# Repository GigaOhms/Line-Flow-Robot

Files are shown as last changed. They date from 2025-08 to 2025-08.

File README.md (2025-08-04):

# Line Flow Bot

**Line Flow Bot** là một robot dò line mini được thiết kế để học tập và nghiên cứu về PCB design, các thuật toán điều khiển nhúng PID, RTOS. Dự án này được tham khảo và chỉnh sửa từ project: [Mini Line Flow Robot – MQCR Excel](https://bitbucket.org/mqcrexcel/mini-line-flow-robot/).

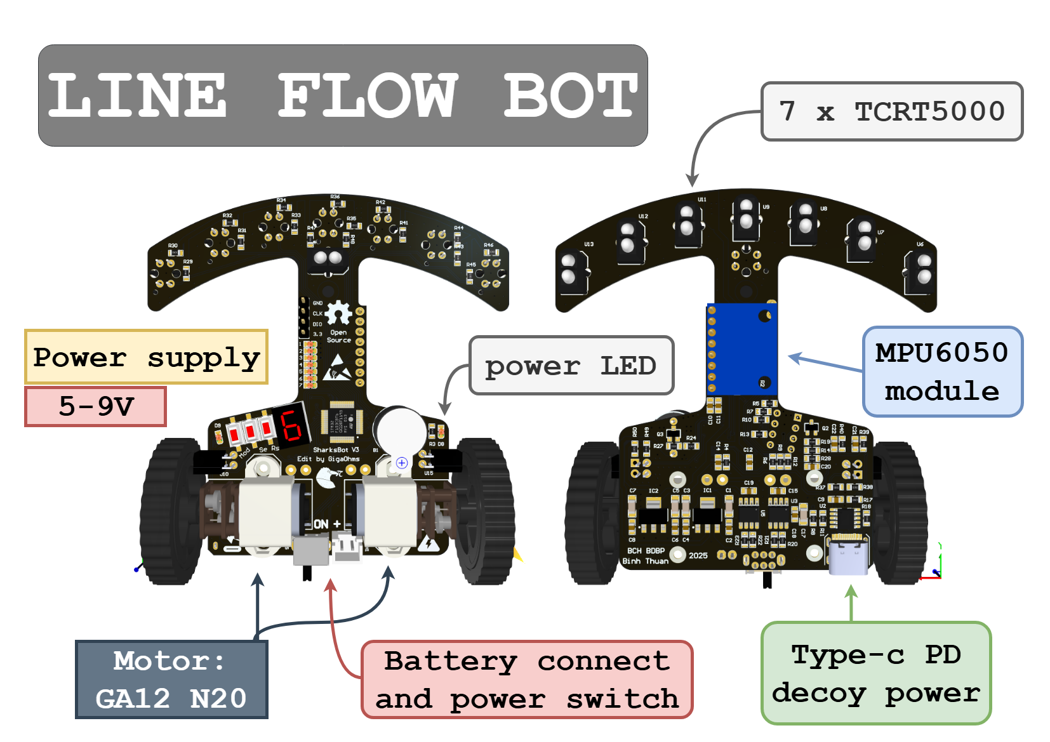
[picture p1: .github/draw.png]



---

## 🧠 Vi điều khiển (MCU)

- **STM32F103C8T6**: ARM Cortex-M3
- Tốc độ xung nhịp: 72 MHz

---

## 🔋 Cấp nguồn

- Điện áp hoạt động: **5–9V**, từ pin Li-ion/LiPo hoặc usb type-C PD protocol.
- Mạch cấp nguồn gồm:
  - **2 x AMS1117**: chuyển từ 5V hoặc 9V xuống 5V và 3.3V 
  - **CH224K (USB Type-C PD Sink)**: cấu hình lấy ra 9V từ cổng USB PD thông qua thiết lập cấu hình điện trở.
  - Công tắc nguồn

---

## ⚙️ Phần cứng chính

### 🚗 Động cơ

- **2 x GA12 N20 500 RPM**
  - Điện áp hoạt động: 5-9V
  - Kết nối qua mạch **2 cầu H** sử dụng **L9110S**

### 🔍 Cảm biến dò line

- **8 x TCRT5000**
  - 7 cảm biến dùng để dò line đen-trắng
  - 1 cảm biến riêng để nhận tín hiệu bắt đầu

### 📦 Cảm biến gia tốc

- **GY-521 (MPU6050)**
  - Gia tốc kế + con quay hồi chuyển (6 DOF)
  - Giao tiếp I2C

### 📟 Hiển thị

- **LED 7 đoạn**
- **LED trạng thái rời**
- **LED nguồn 9V PD decoy**

### 🔘 Nút nhấn

- 2 nút nhấn dùng để cấu hình chế độ chạy hoặc hiệu chỉnh cảm biến

---

## 🧩 Giao tiếp và kết nối

- **SWD**: giao tiếp nạp chương trình và debug cho STM32
- **I2C**: giao tiếp với MPU6050

---

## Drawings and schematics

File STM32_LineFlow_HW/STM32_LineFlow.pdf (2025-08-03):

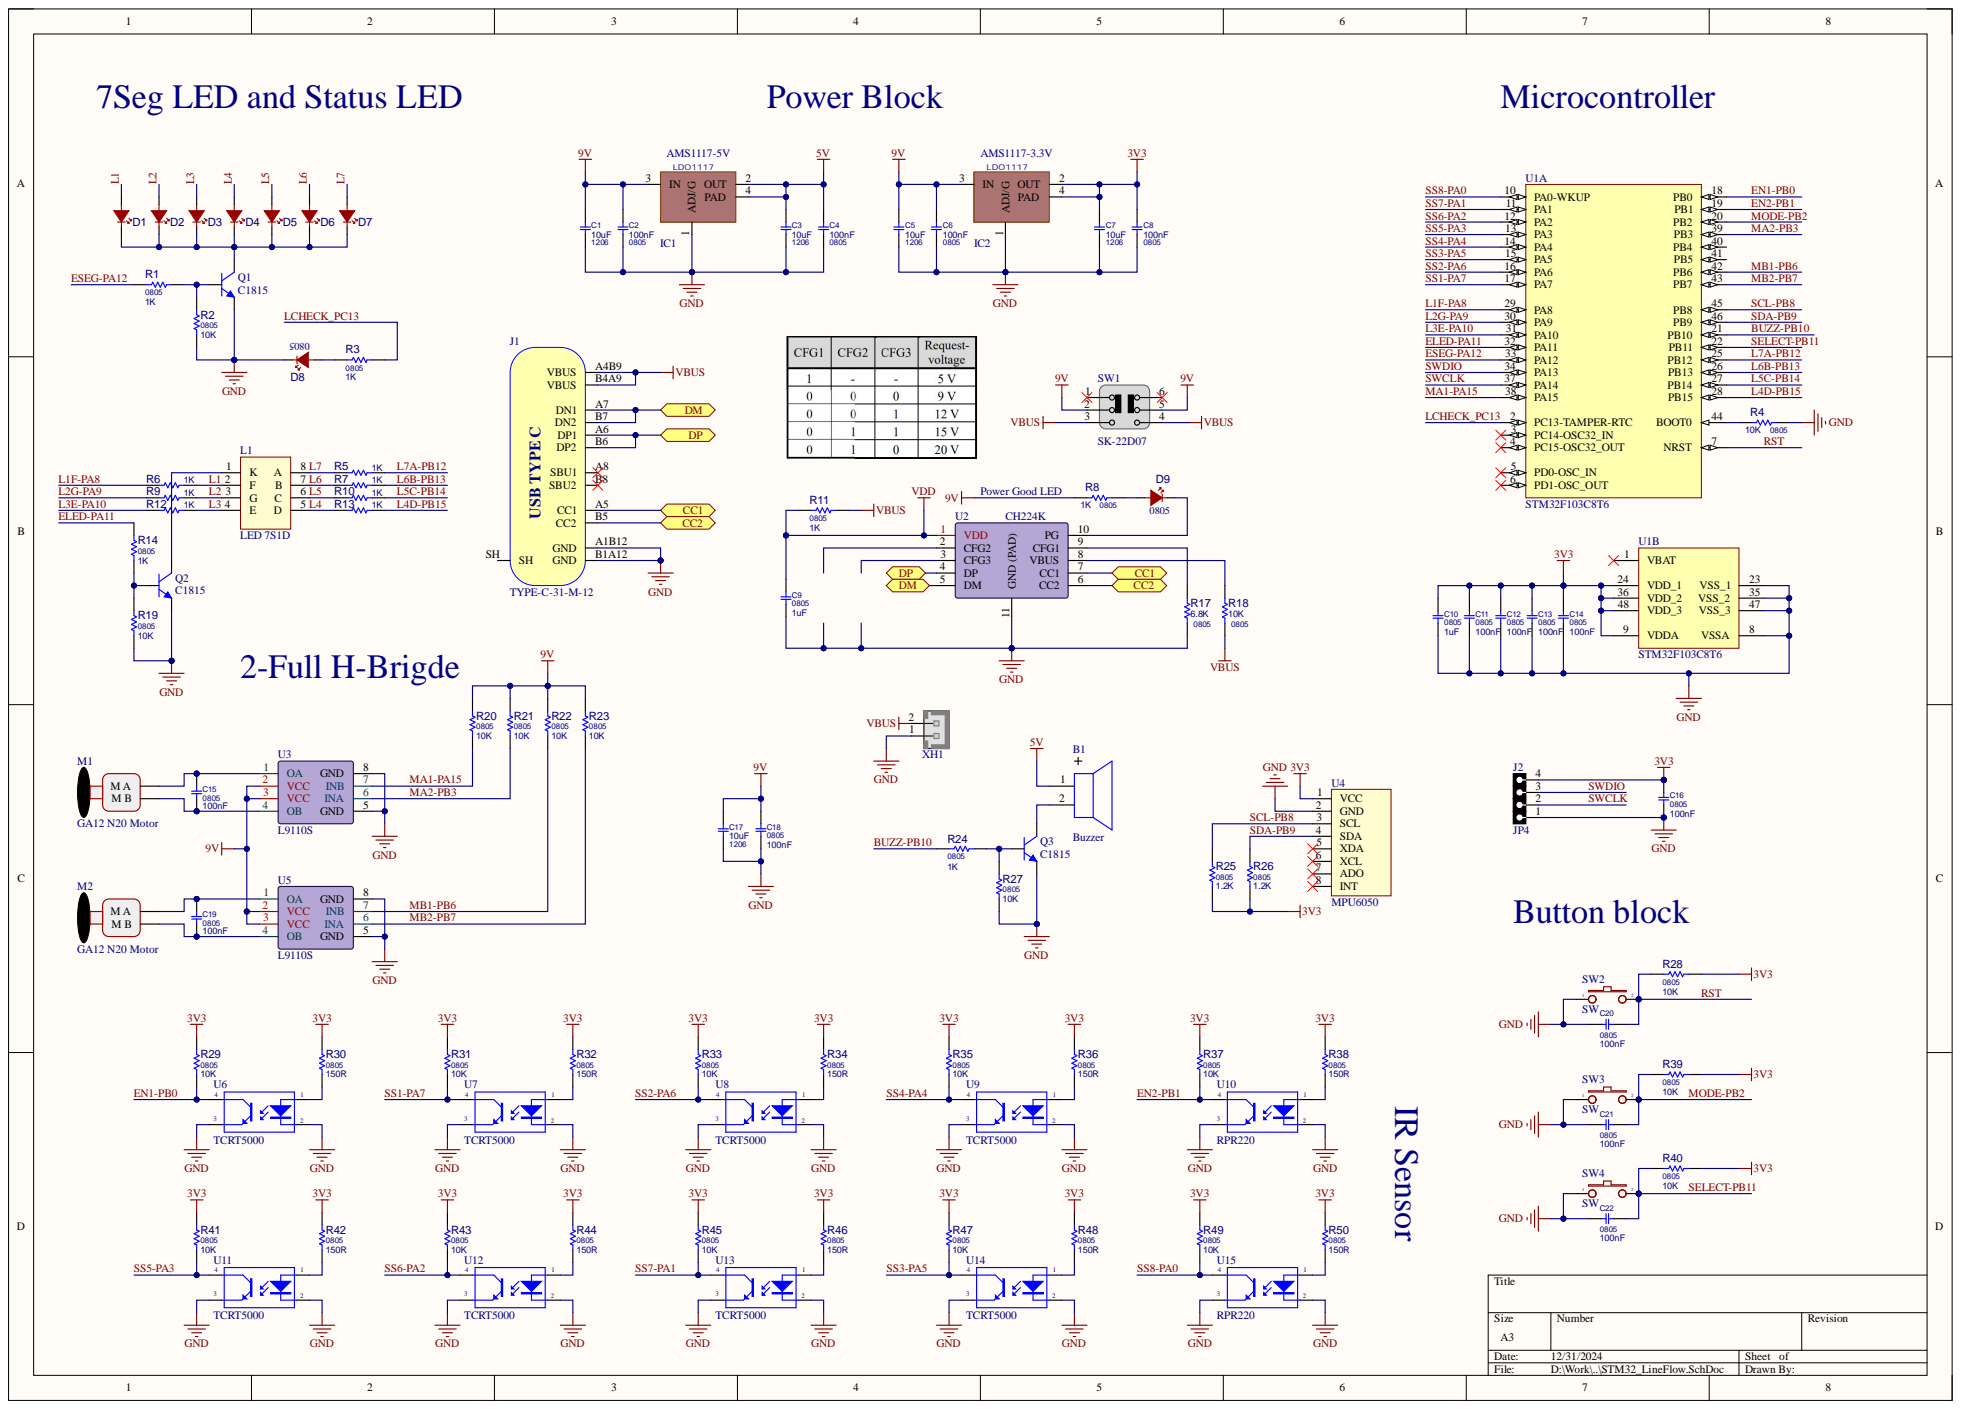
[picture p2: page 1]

7Seg LED and Status LED

SDA-PB9 | SDA 4

XDA 5

Comment | Description | Designator | Footprint | LibRef | Quantity | VALUE
0805 | LEDRed SMD | D1, D2, D3, D4, D5, D6, D7, D8, D9 | LED0805RED | LEDRed SMD | 9
Buzzer | Buzzer | B1 | Buzzer | Buzzer | 1
C1815 | BJTC1815Trans NPN 50V150mATO-92 | Q1, Q2, Q3 | 2SC1815-HF | BJT2SC1815 | 3
CH224K | CH224KUSBPD Decoy, USBPower Delivery Decoy | U2 | ESOP-10CHAY | CH224K | 1
GA12N20Motor | GA12N20Metal Gear Motor | M1, M2 | Motor GA-12Type3, Motor GA-12Type2 | GA12N20Motor | 2
JP4 | JP4 | J2 | JP_4PIN | JP4 | 1
L9110S | L9110 | U3, U5 | SOIC-8 | L9110 | 2
LED7S1D | | L1 | LED7S1D0.28" | LED7S1D | 1
MPU6050 | MPU6050Module | U4 | MPU-6050 | MPU6050 | 1
RPR220 | | U10, U15 | RPR220 | RPR220 | 2
SK-22D07 | SWSK-22D07Công Tắc Trượt 6Chân Xuyên Lỗ ON-ON 2P2T1A | SW1 | SK-22D07 | SWSK-22D07 | 1
STM32F103C8T6 | ARMCortex-M332-bit MCU, 64KBFlash, 20 KBInternal RAM, 37 I/Os, 48-pin LQFP, -40 to 85degC, Tray | U1 | STM-LQFP48_N | STM32F103C8T6AB | 1
TCRT5000 | TCRT5000Cảm Biến HồngNgoại Phản Xạ | U6, U7, U8, U9, U11, U12, U13, U14 | TCRT5000 | TCRT5000 | 8
TYPE-C-31-M-12 | USBTypeCConnector Horizontal SMT | J1 | TYPE-C-31-M-12 | TYPE-C-31-M-12 | 1
0805 | RESSMD | R1, R3, R5, R6, R7, R8, R9, R10, R11, R12, R13, R14, R24 | R0805 | RESSMD | 13 1K
0805 | CAPSMD | C9, C10 | cap_0805 | CAPSMD | 2 1uF
0805 | RESSMD | R25, R26 | R0805 | RESSMD | 2 1.2K
0805 | RESSMD | R17 | R0805 | RESSMD | 1 6.8K
0805 | RESSMD | R2, R4, R18, R19, R20, R21, R22, R23, R27, R28, R29, R31, R33, R35, R37, R39, R40, R41, R43, R45, R47, R49 | R0805 | RESSMD | 22 10K
1206 | CAPSMD | C1, C3, C5, C7, C17 | cap_1206 | CAPSMD | 5 10uF
0805 | CAPSMD | C2, C4, C6, C8, C11, C12, C13, C14, C15, C16, C18, C19, C20, C21, C22 | cap_0805 | CAPSMD | 15 100nF
0805 | RESSMD | R30, R32, R34, R36, R38, R42, R44, R46, R48, R50 | R0805 | RESSMD | 10 150R
HHDR_2 | XH2JST-XHpitch: 2.5mm | XH1 | XH_2 | XH_2 | 1 HHDR_2
AMS1117-3.3V | LDO1117Availablein 1.8V, 2.5V, 2.85V, 3.3V, 5V, and AdjustableVersions | IC2 | SOT223 | LDO1117 | 1 LM317
AMS1117-5V | LDO1117Availablein 1.8V, 2.5V, 2.85V, 3.3V, 5V, and AdjustableVersions | IC1 | SOT223 | LDO1117 | 1 LM317
SW | Switch button 2pin | SW2, SW3, SW4 | SW-SMD | SW2 | 3 SWchip 2pin

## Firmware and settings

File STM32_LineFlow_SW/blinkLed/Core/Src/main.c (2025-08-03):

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
/* Includes ------------------------------------------------------------------*/
#include "main.h"
#include "cmsis_os.h"

/* USER CODE BEGIN Includes */
#include "led.h"
#include "giga_func.h"
#include "i2c_slave.h"
/* USER CODE END Includes */

ADC_HandleTypeDef hadc1;
DMA_HandleTypeDef hdma_adc1;

I2C_HandleTypeDef hi2c1;

TIM_HandleTypeDef htim2;
TIM_HandleTypeDef htim4;

osThreadId WriteGPIO_PWMHandle;
osThreadId ReadAnalogSensoHandle;
osThreadId ReadGyroSensorHandle;
/* USER CODE BEGIN PV */

#define STOP_CAR 0
#define RUN_CAR 1

volatile uint16_t analog_val[10];
uint8_t but_mode = 0;
uint8_t but_select = 0;
uint8_t cnt_mode = 0;
uint8_t cnt_select = 0;
uint8_t start_car = 0;


		uint8_t data_gyro[6];
		volatile int16_t x_gyro;
		volatile int16_t y_gyro;
		volatile int16_t z_gyro;

/*
void bzEnable(void);
void mForward(void);
void mBackward(void);
void mStop(void);
void mLeft(void);
void mRight(void);
void loop_7seg(void);
*/

/* USER CODE END PV */

void SystemClock_Config(void);
static void MX_GPIO_Init(void);
static void MX_DMA_Init(void);
static void MX_TIM2_Init(void);
static void MX_TIM4_Init(void);
static void MX_I2C1_Init(void);
static void MX_ADC1_Init(void);
void Write_IO_PWM(void const * argument);
void Read_Analog_Ssr(void const * argument);
void Read_Gyro_Ssr(void const * argument);

/**
  * @brief  The application entry point.
  * @retval int
  */
int main(void)
{

  /* MCU Configuration--------------------------------------------------------*/

  /* Reset of all peripherals, Initializes the Flash interface and the Systick. */
  HAL_Init();

  /* Configure the system clock */
  SystemClock_Config();

  /* Initialize all configured peripherals */
  MX_GPIO_Init();
  MX_DMA_Init();
  MX_TIM2_Init();
  MX_TIM4_Init();
  MX_I2C1_Init();
  MX_ADC1_Init();
  /* USER CODE BEGIN 2 */
	
	HAL_TIM_PWM_Start (&htim2, TIM_CHANNEL_1);
	HAL_TIM_PWM_Start (&htim2, TIM_CHANNEL_2);
	HAL_TIM_PWM_Start (&htim4, TIM_CHANNEL_1);
	HAL_TIM_PWM_Start (&htim4, TIM_CHANNEL_2);
	
	//if (HAL_I2C_EnableListen_IT(&hi2c1) != HAL_OK)
		//Error_Handler();
	
	/*
	HAL_StatusTypeDef ret = HAL_I2C_IsDeviceReady(&hi2c1, (0x68<<1) + 0, 1, 100);
	if (ret == HAL_OK)
		HAL_GPIO_WritePin(ledPC13_GPIO_Port, ledPC13_Pin, GPIO_PIN_SET);
	else HAL_GPIO_WritePin(ledPC13_GPIO_Port, ledPC13_Pin, GPIO_PIN_RESET);
	
	uint8_t temp_data = 0;
	ret = HAL_I2C_Mem_Write(&hi2c1, (0x68<<1) + 0, 27, 1, &temp_data, 1, 100);
	if (ret == HAL_OK) {
		HAL_Delay(200);
		HAL_GPIO_WritePin(ledPC13_GPIO_Port, ledPC13_Pin, GPIO_PIN_RESET);
		HAL_Delay(200);
		HAL_GPIO_WritePin(ledPC13_GPIO_Port, ledPC13_Pin, GPIO_PIN_SET);
		HAL_Delay(200);
		HAL_GPIO_WritePin(ledPC13_GPIO_Port, ledPC13_Pin, GPIO_PIN_RESET);
		HAL_Delay(200);
		HAL_GPIO_WritePin(ledPC13_GPIO_Port, ledPC13_Pin, GPIO_PIN_SET);
	}
	else HAL_GPIO_WritePin(ledPC13_GPIO_Port, ledPC13_Pin, GPIO_PIN_RESET);
	
	temp_data = 0;
	ret = HAL_I2C_Mem_Write(&hi2c1, (0x68<<1) + 0, 28, 1, &temp_data, 1, 100);
	if (ret == HAL_OK) {
		HAL_Delay(200);
		HAL_GPIO_WritePin(ledPC13_GPIO_Port, ledPC13_Pin, GPIO_PIN_RESET);
		HAL_Delay(200);
		HAL_GPIO_WritePin(ledPC13_GPIO_Port, ledPC13_Pin, GPIO_PIN_SET);
		HAL_Delay(200);
		HAL_GPIO_WritePin(ledPC13_GPIO_Port, ledPC13_Pin, GPIO_PIN_RESET);
		HAL_Delay(200);
		HAL_GPIO_WritePin(ledPC13_GPIO_Port, ledPC13_Pin, GPIO_PIN_SET);
	}
	else HAL_GPIO_WritePin(ledPC13_GPIO_Port, ledPC13_Pin, GPIO_PIN_RESET);
	
	temp_data = 0;
	ret = HAL_I2C_Mem_Write(&hi2c1, (0x68<<1) + 0, 107, 1, &temp_data, 1, 100);
	if (ret == HAL_OK) {
		HAL_Delay(200);
		HAL_GPIO_WritePin(ledPC13_GPIO_Port, ledPC13_Pin, GPIO_PIN_RESET);
		HAL_Delay(200);
		HAL_GPIO_WritePin(ledPC13_GPIO_Port, ledPC13_Pin, GPIO_PIN_SET);
		HAL_Delay(200);
		HAL_GPIO_WritePin(ledPC13_GPIO_Port, ledPC13_Pin, GPIO_PIN_RESET);
		HAL_Delay(200);
		HAL_GPIO_WritePin(ledPC13_GPIO_Port, ledPC13_Pin, GPIO_PIN_SET);
	}
	else HAL_GPIO_WritePin(ledPC13_GPIO_Port, ledPC13_Pin, GPIO_PIN_RESET);
	*/
	
	
	HAL_GPIO_WritePin(ledPC13_GPIO_Port, ledPC13_Pin, GPIO_PIN_SET);
	Show_7Seg(0);
	stop_motor();
	
	
  /* USER CODE END 2 */

  /* USER CODE BEGIN RTOS_MUTEX */
  /* add mutexes, ... */
  /* USER CODE END RTOS_MUTEX */

  /* USER CODE BEGIN RTOS_SEMAPHORES */
  /* add semaphores, ... */
  /* USER CODE END RTOS_SEMAPHORES */

  /* USER CODE BEGIN RTOS_TIMERS */
  /* start timers, add new ones, ... */
  /* USER CODE END RTOS_TIMERS */

  /* USER CODE BEGIN RTOS_QUEUES */
  /* add queues, ... */
  /* USER CODE END RTOS_QUEUES */

  /* Create the thread(s) */
  /* definition and creation of WriteGPIO_PWM */
  osThreadDef(WriteGPIO_PWM, Write_IO_PWM, osPriorityLow, 0, 128);
  WriteGPIO_PWMHandle = osThreadCreate(osThread(WriteGPIO_PWM), NULL);

  /* definition and creation of ReadAnalogSenso */
  osThreadDef(ReadAnalogSenso, Read_Analog_Ssr, osPriorityBelowNormal, 0, 128);
  ReadAnalogSensoHandle = osThreadCreate(osThread(ReadAnalogSenso), NULL);

  /* definition and creation of ReadGyroSensor */
  osThreadDef(ReadGyroSensor, Read_Gyro_Ssr, osPriorityLow, 0, 128);
  ReadGyroSensorHandle = osThreadCreate(osThread(ReadGyroSensor), NULL);

  /* USER CODE BEGIN RTOS_THREADS */
  /* add threads, ... */
  /* USER CODE END RTOS_THREADS */

  /* Start scheduler */
  osKernelStart();

  /* We should never get here as control is now taken by the scheduler */

  /* Infinite loop */
  /* USER CODE BEGIN WHILE */
  while (1)
  {
    /* USER CODE END WHILE */

    /* USER CODE BEGIN 3 */

		/*
		HAL_I2C_Mem_Read(&hi2c1, (0x68<<1) + 1, 67, 1, data_gyro, 6, 100);
		x_acc = ((int16_t)data_gyro[0] << 8) + data_gyro[1];
		y_acc = ((int16_t)data_gyro[2] << 8) + data_gyro[3];
		z_acc = ((int16_t)data_gyro[4] << 8) + data_gyro[5];
		HAL_Delay(10);
		*/
		
  }
	
  /* USER CODE END 3 */
}

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
/* USER CODE BEGIN 4 */

/*
void bzEnable(void) {
	bzState = 1;
	HAL_GPIO_WritePin(GPIOB, GPIO_PIN_10, bzState);
	bzTime = HAL_GetTick() + 100;
}

void loop_7seg(void) {
	if ((uint32_t)(HAL_GetTick() - led7Time) > 100) {
		led7Time = HAL_GetTick();
		Show_1Seg(counter);
		counter++;
		if (counter >= 7)
			counter = 1;
	}
}

void mRight(void) {
	TIM2 ->CCR1 = 500;
	TIM2 ->CCR2 = 0;	
	TIM4 ->CCR1 = 0;
	TIM4 ->CCR2 = 500;	
}

void mLeft(void) {
	TIM2 ->CCR1 = 0;
	TIM2 ->CCR2 = 500;	
	TIM4 ->CCR1 = 500;
	TIM4 ->CCR2 = 0;	
}

void mStop(void) {
	TIM2 ->CCR1 = 0;
	TIM2 ->CCR2 = 0;	
	TIM4 ->CCR1 = 0;
	TIM4 ->CCR2 = 0;		
}

void mForward(void) {
	TIM2 ->CCR1 = 500;
	TIM2 ->CCR2 = 0;	
	TIM4 ->CCR1 = 500;
	TIM4 ->CCR2 = 0;	
}

void mBackward(void) {
	TIM2 ->CCR1 = 0;
	TIM2 ->CCR2 = 500;	
	TIM4 ->CCR1 = 0;
	TIM4 ->CCR2 = 500;	
}
*/

/* USER CODE END 4 */

/* USER CODE BEGIN Header_Write_IO_PWM */
/**
  * @brief  Function implementing the WriteGPIO_PWM thread.
  * @param  argument: Not used
  * @retval None
  */
/* USER CODE END Header_Write_IO_PWM */
void Write_IO_PWM(void const * argument)
{
  /* USER CODE BEGIN 5 */
  /* Infinite loop */
  for(;;)
  {
		if (analog_val[5] <= 1000)
			start_car = RUN_CAR;
    osDelay(1);
  }
  /* USER CODE END 5 */
}

/* USER CODE BEGIN Header_Read_Analog_Ssr */
/**
* @brief Function implementing the ReadAnalogSenso thread.
* @param argument: Not used
* @retval None
*/
/* USER CODE END Header_Read_Analog_Ssr */
void Read_Analog_Ssr(void const * argument)
{
  /* USER CODE BEGIN Read_Analog_Ssr */
  /* Infinite loop */
  for(;;)
  {
		HAL_ADC_Start_DMA(&hadc1, (uint32_t*)analog_val, 10);
    osDelay(1);
  }
  /* USER CODE END Read_Analog_Ssr */
}

/* USER CODE BEGIN Header_Read_Gyro_Ssr */
/**
* @brief Function implementing the ReadGyroSensor thread.
* @param argument: Not used
* @retval None
*/
/* USER CODE END Header_Read_Gyro_Ssr */
void Read_Gyro_Ssr(void const * argument)
{
  /* USER CODE BEGIN Read_Gyro_Ssr */
  /* Infinite loop */
  for(;;)
  {
		read_button();
		if (cnt_select > 1 && cnt_select % 2 == 0) {
			loop_7seg();
			operating_mode();
		}
    osDelay(1);
  }
  /* USER CODE END Read_Gyro_Ssr */
}

/**
  * @brief  Period elapsed callback in non blocking mode
  * @note   This function is called  when TIM3 interrupt took place, inside
  * HAL_TIM_IRQHandler(). It makes a direct call to HAL_IncTick() to increment
  * a global variable "uwTick" used as application time base.
  * @param  htim : TIM handle
  * @retval None
  */
void HAL_TIM_PeriodElapsedCallback(TIM_HandleTypeDef *htim)
{
  if (htim->Instance == TIM3) {
    HAL_IncTick();
  }
}

/**
  * @brief  This function is executed in case of error occurrence.
  * @retval None
  */
void Error_Handler(void)
{
  /* USER CODE BEGIN Error_Handler_Debug */
  /* User can add his own implementation to report the HAL error return state */
  __disable_irq();
  while (1)
  {
  }
  /* USER CODE END Error_Handler_Debug */
}

#ifdef  USE_FULL_ASSERT
/**
  * @brief  Reports the name of the source file and the source line number
  *         where the assert_param error has occurred.
  * @param  file: pointer to the source file name
  * @param  line: assert_param error line source number
  * @retval None
  */
void assert_failed(uint8_t *file, uint32_t line)
{
  /* USER CODE BEGIN 6 */
  /* User can add his own implementation to report the file name and line number,
     ex: printf("Wrong parameters value: file %s on line %d\r\n", file, line) */
  /* USER CODE END 6 */
}
#endif /* USE_FULL_ASSERT */

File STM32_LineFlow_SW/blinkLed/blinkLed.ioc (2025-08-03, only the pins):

Mcu.UserName=STM32F103C8Tx
PA0-WKUP.GPIO_Label=SSSTART
PA0-WKUP.Signal=ADCx_IN0
PA1.GPIO_Label=SS2
PA1.Signal=ADCx_IN1
PA10.GPIO_Label=L1F
PA10.Signal=GPIO_Output
PA11.GPIO_Label=EN7LED
PA11.Signal=GPIO_Output
PA12.GPIO_Label=EN7SEG
PA12.Signal=GPIO_Output
PA13.Signal=SYS_JTMS-SWDIO
PA14.Signal=SYS_JTCK-SWCLK
PA15.Signal=S_TIM2_CH1_ETR
PA2.GPIO_Label=SS3
PA2.Signal=ADCx_IN2
PA3.GPIO_Label=SS4
PA3.Signal=ADCx_IN3
PA4.GPIO_Label=SS5
PA4.Signal=ADCx_IN4
PA5.GPIO_Label=SS6
PA5.Signal=ADCx_IN5
PA6.GPIO_Label=SS7
PA6.Signal=ADCx_IN6
PA7.GPIO_Label=SS8
PA7.Signal=ADCx_IN7
PA8.GPIO_Label=L3E
PA8.Signal=GPIO_Output
PA9.GPIO_Label=L2G
PA9.Signal=GPIO_Output
PB0.GPIO_Label=ENCO1
PB0.Signal=ADCx_IN8
PB1.GPIO_Label=ENCO2
PB1.Signal=ADCx_IN9
PB10.GPIO_Label=BUZZ
PB10.Signal=GPIO_Output
PB11.GPIO_Label=SELECT
PB11.Signal=GPIO_Input
PB12.GPIO_Label=L7A
PB12.Signal=GPIO_Output
PB13.GPIO_Label=L6B
PB13.Signal=GPIO_Output
PB14.GPIO_Label=L5C
PB14.Signal=GPIO_Output
PB15.GPIO_Label=L4D
PB15.Signal=GPIO_Output
PB2.GPIO_Label=MODE
PB2.Signal=GPIO_Input
PB3.Signal=S_TIM2_CH2
PB6.Signal=S_TIM4_CH1
PB7.Signal=S_TIM4_CH2
PB8.Signal=I2C1_SCL
PB9.Signal=I2C1_SDA
PC13-TAMPER-RTC.GPIO_Label=ledPC13
PC13-TAMPER-RTC.Signal=GPIO_Output

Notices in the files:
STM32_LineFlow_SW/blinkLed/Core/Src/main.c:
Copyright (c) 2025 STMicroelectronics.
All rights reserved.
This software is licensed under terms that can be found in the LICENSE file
